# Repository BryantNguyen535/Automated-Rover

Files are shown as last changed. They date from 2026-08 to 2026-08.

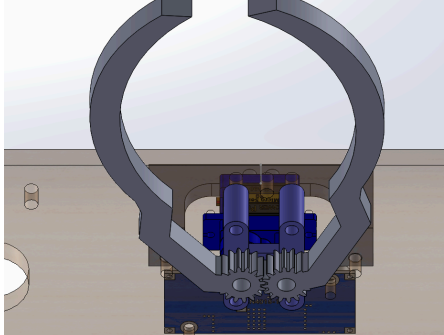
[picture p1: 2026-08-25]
Images/ClawDesign.png

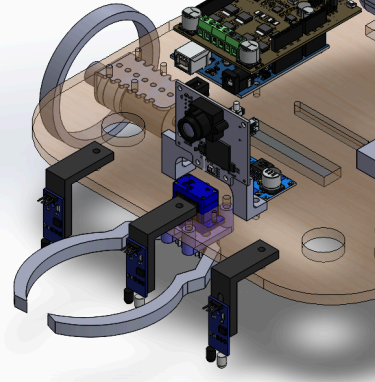
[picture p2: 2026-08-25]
Images/CameraMount.png

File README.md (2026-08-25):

# ZotGPT: Gerbil Portable Transportation

An autonomous line-tracking and object-retrieval rover designed for the ENGR 7B course at the University of California, Irvine (Winter 2023)[cite: 1].

## Team Members
* **Bryant Nguyen** – Team Captain, CAD, Fabrication[cite: 1]
* **Maddox Reyes** – CAD, Electronics[cite: 1]
* **Cole Tateyama** – Electronics, Coding[cite: 1]
* **Rafael Cortes** – Electronics, Coding[cite: 1]
* **Ben Vu** – CAD, Fabrication[cite: 1]

## Overview
ZotGPT is a single-layer, beetle-inspired autonomous rover engineered for speed, stability, and fast line navigation[cite: 1]. The system uses three line-tracking IR sensors to navigate a course and transitions to a Pixy2 camera vision system to center, approach, and retrieve a target colored can using a custom 3D-printed claw[cite: 1].

## Technical Specifications
| Parameter | Value / Specification |
| :--- | :--- |
| **Dimensions** | 15.25 in × 11.27 in[cite: 1] |
| **Chassis Material** | 1/4" Baltic Birch Plywood[cite: 1] |
| **Total Weight** | 1,068.9 g (Stall Limit: 1,650 g)[cite: 1] |
| **Center of Mass** | 5.01 in (width offset), 6.36 in (from back)[cite: 1] |
| **Total Cost** | $263.41 (Budget: <$300)[cite: 1] |
| **Drive Motors** | Dual Pololu 34:1 Gearmotors[cite: 1] |
| **Wheels** | 80mm × 10mm Drive Wheels + 3/4" Caster Wheel[cite: 1] |
| **Microcontroller** | Arduino Uno + Motor Driver Shield[cite: 1] |
| **Sensors & Vision** | Pixy2 Camera, 3× IR Line Sensors[cite: 1] |
| **Actuation** | SG90 Micro Servo (Gear-Driven Claw Mechanism)[cite: 1] |

## Key Features & Design Highlights
* **Optimized Speed & Torque:** Utilizes 34:1 gearmotors paired with 80mm wheels to maximize distance covered per motor rotation while staying below stall weight constraints[cite: 1].
* **Single-Layer Wooden Chassis:** Built with Baltic birch plywood for a lightweight frame and straightforward access to electronics[cite: 1].
* **Adjustable Sensor Placement:** Front-mounted IR sensors positioned close to the ground provide immediate surface readouts, preventing motor signal lag[cite: 1].
* **Elevated Camera Mount:** Custom 3D-printed bracket raises the Pixy2 camera for a high vantage point to detect colored targets reliably[cite: 1].
* **Regulated Power Delivery:** Features an inline buck converter to regulate voltage to the micro servo and eliminate power draw issues[cite: 1].

## System Architecture & Algorithm Design

### State Control Logic
1. **Line Following Mode:**
   * Continuously polls 3 front-mounted IR sensors[cite: 1].
   * If left IR sensor detects line: Steering corrects right[cite: 1].
   * If right IR sensor detects line: Steering corrects left[cite: 1].
   * If middle sensor detects line: Rover drives straight[cite: 1].
   * If all 3 sensors trigger HIGH: Controller switches state to PixyCam tracking[cite: 1].

2. **PixyCam Object Tracking & Grab Mode:**
   * Pixy2 camera processes the pre-programmed color signature of the target[cite: 1].
   * Adjusts left/right motor speeds until target is centered horizontally[cite: 1].
   * Drives forward until object area reaches a predefined threshold distance[cite: 1].
   * Activates SG90 servo to actuate gears and close claw onto the target[cite: 1].

## Bill of Materials (BOM)
| Component | Qty | Extended Price |
| :--- | :---: | :---: |
| Arduino Uno | 1 | $27.60[cite: 1] |
| Motor Driver Shield | 1 | $22.55[cite: 1] |
| Pixy Cam2 | 1 | $69.96[cite: 1] |
| Pololu 34:1 Gearmotors | 1 | $29.95[cite: 1] |
| 80mm x 10mm Wheels | 1 | $9.95[cite: 1] |
| 3D Printing Components | 1 | $32.00[cite: 1] |
| 1/4" Baltic Birch Plywood (16"x10") | 1 | $2.78[cite: 1] |
| Zeee Battery Pack | 1 | $17.50[cite: 1] |
| D-Planet Buck Converter | 1 | $3.75[cite: 1] |
| IR Line Sensors | 3 | $1.65[cite: 1] |
| SG90 Micro Servo | 1 | $1.75[cite: 1] |
| Miscellaneous (Wiring, Switch, Breadboard, Caster) | – | $26.97[cite: 1] |
| **Grand Total (with 7.75% Tax)** | – | **$263.41**[cite: 1] |

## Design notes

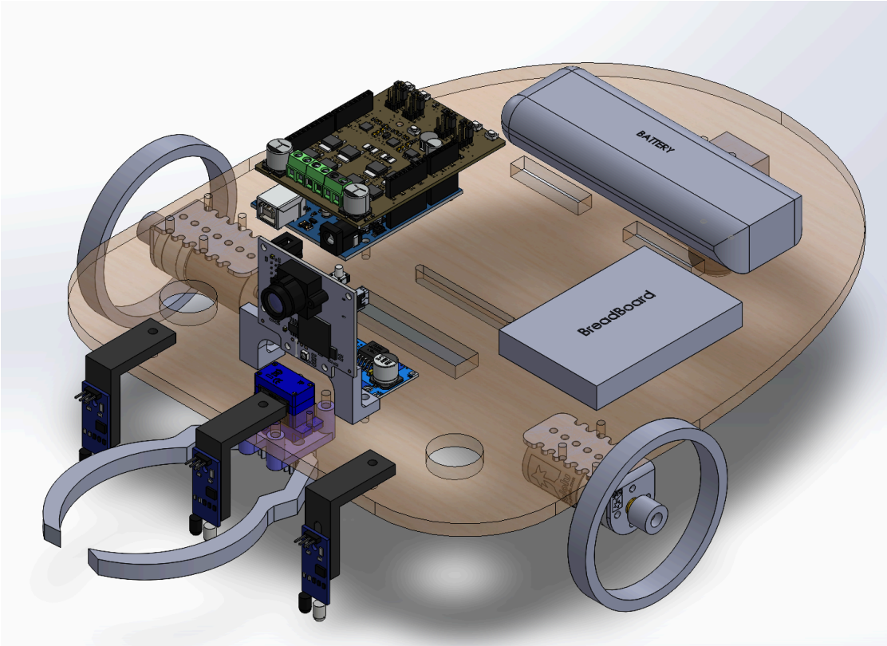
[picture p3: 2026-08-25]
Images/AutomatedRoverFinal.png

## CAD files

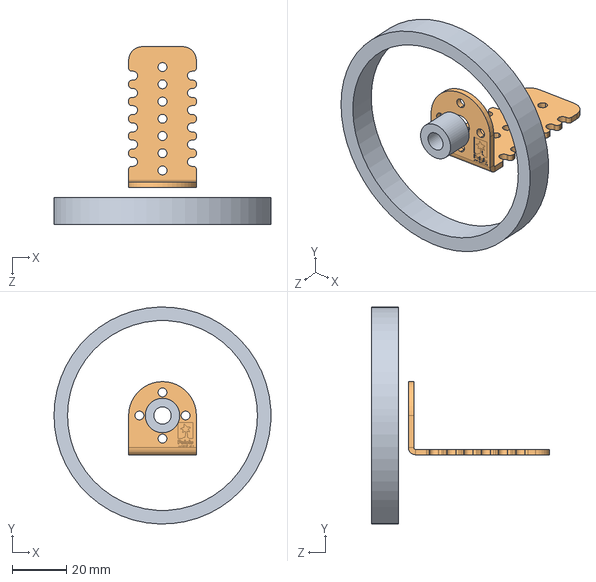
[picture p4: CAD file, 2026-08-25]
CAD files/Gear wheel.SLDASM
80.0 x 80.0 x 65.5 mm
GearmotorBracket
Wheel

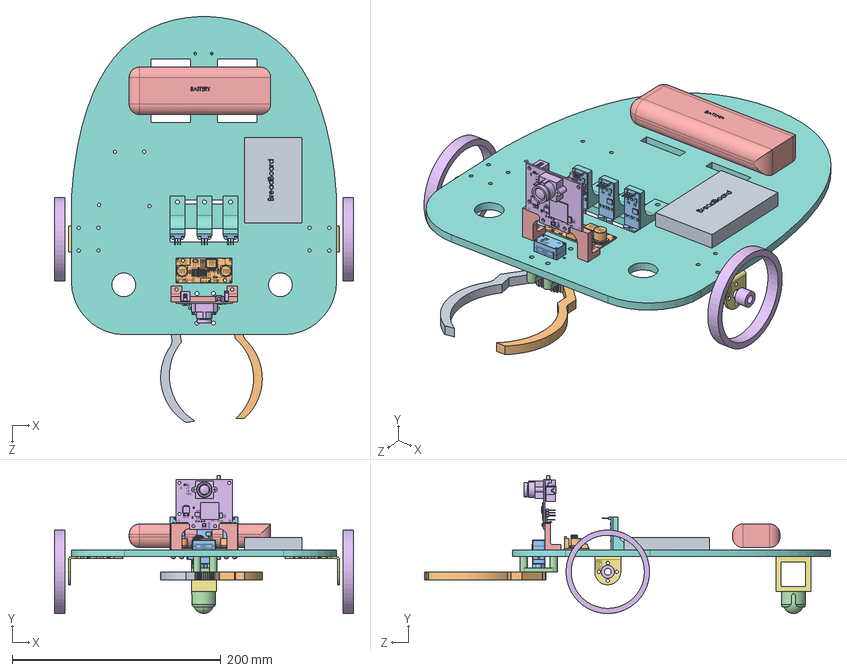
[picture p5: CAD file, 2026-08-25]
CAD files/Automouns rover.SLDASM
286.3 x 132.2 x 389.0 mm
Chassis G
GearmotorBracket x 2
Wheel x 2
part_battery
BallCaster
IRSensor x 3
BuckConverter
BreadBoard
LBracket x 3
Spacer
CMUcam5 Pixy
Double_L_Bracket
Gear_Connector
MicroServo
Gear1
Gear2

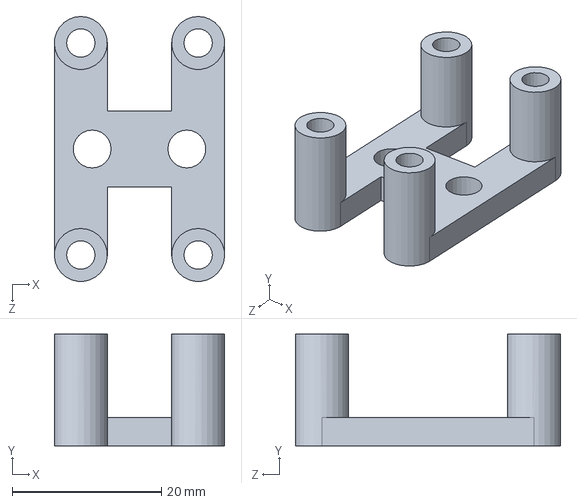
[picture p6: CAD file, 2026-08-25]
CAD files/Gear_Connector.SLDPRT
22.9 x 15.0 x 35.6 mm

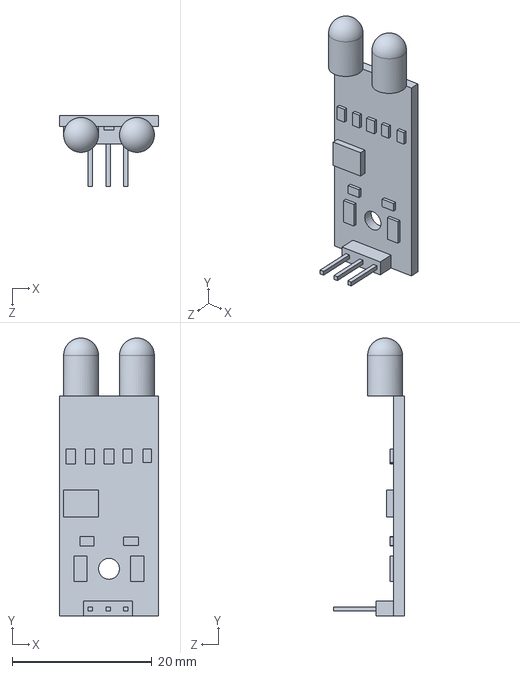
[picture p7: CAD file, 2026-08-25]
CAD files/IRSensor.SLDPRT
14.2 x 39.8 x 10.1 mm

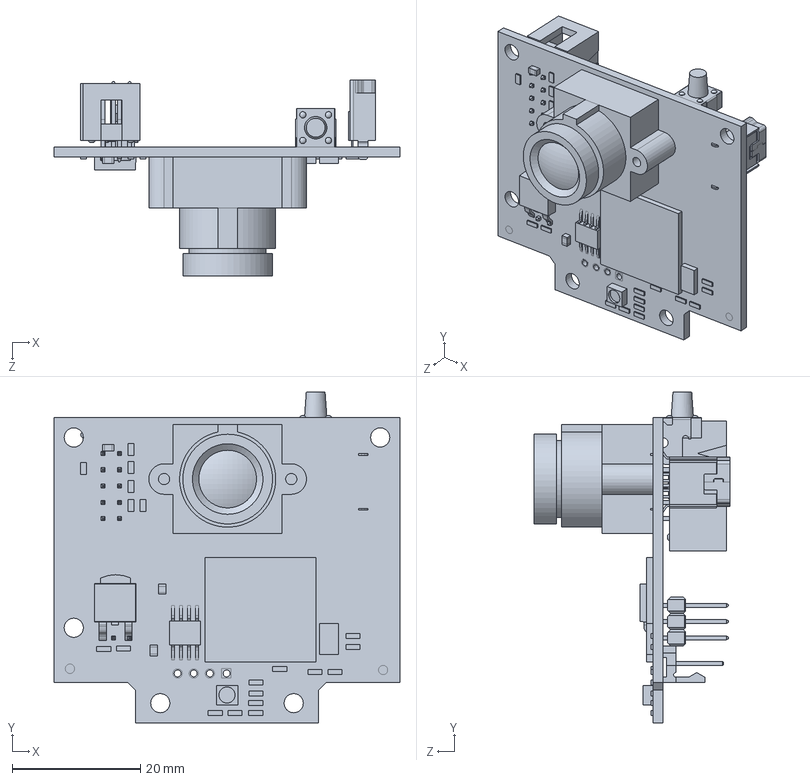
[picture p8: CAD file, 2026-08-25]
CAD files/CMUcam5 Pixy.SLDPRT
54.0 x 51.6 x 30.5 mm

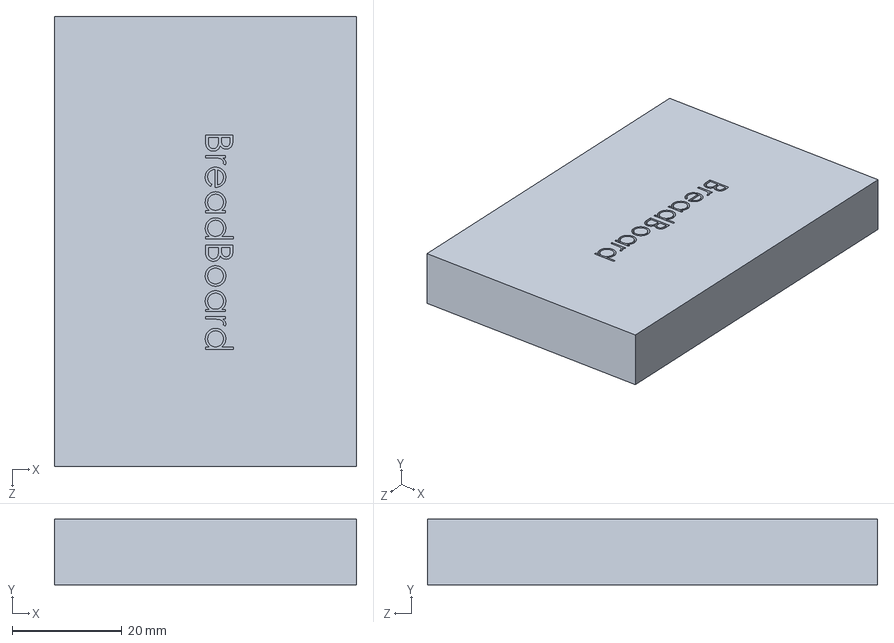
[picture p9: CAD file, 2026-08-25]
CAD files/BreadBoard.SLDPRT
55.0 x 11.9 x 82.0 mm

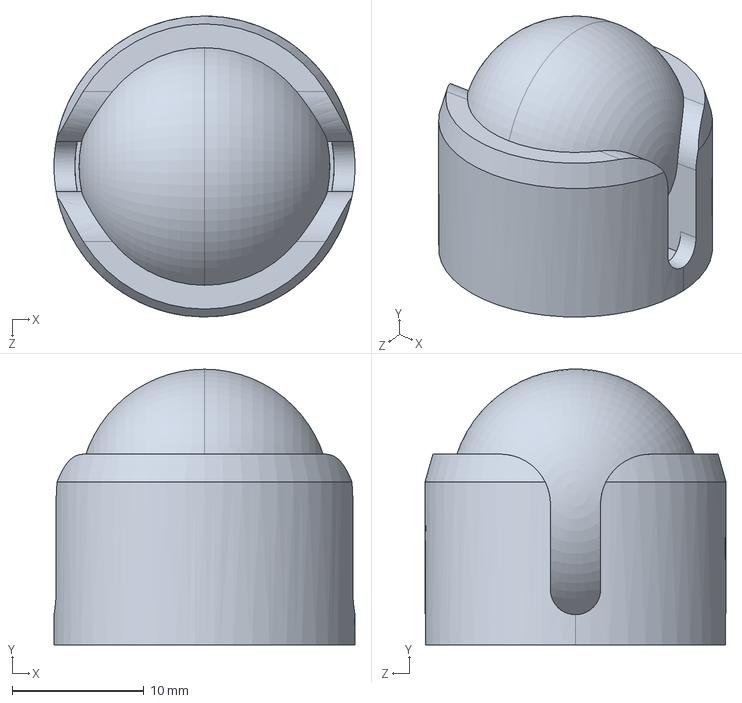
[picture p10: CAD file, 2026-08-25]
CAD files/BallCaster.SLDPRT
22.9 x 20.9 x 22.9 mm

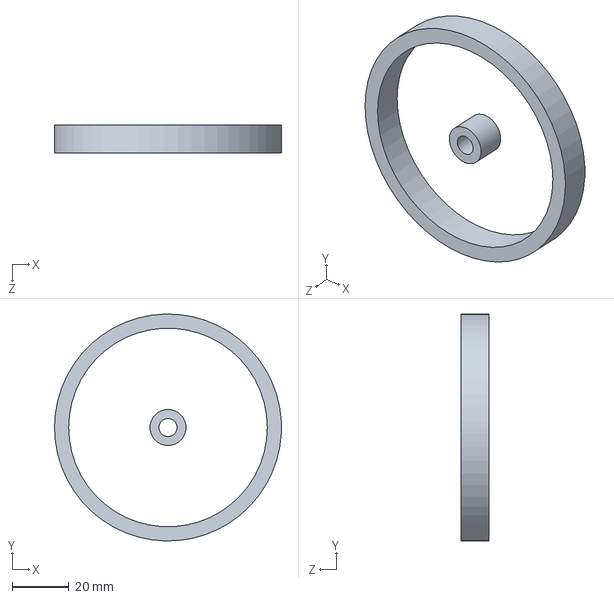
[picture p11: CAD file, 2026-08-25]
CAD files/Wheel.SLDPRT
80.0 x 80.0 x 10.0 mm

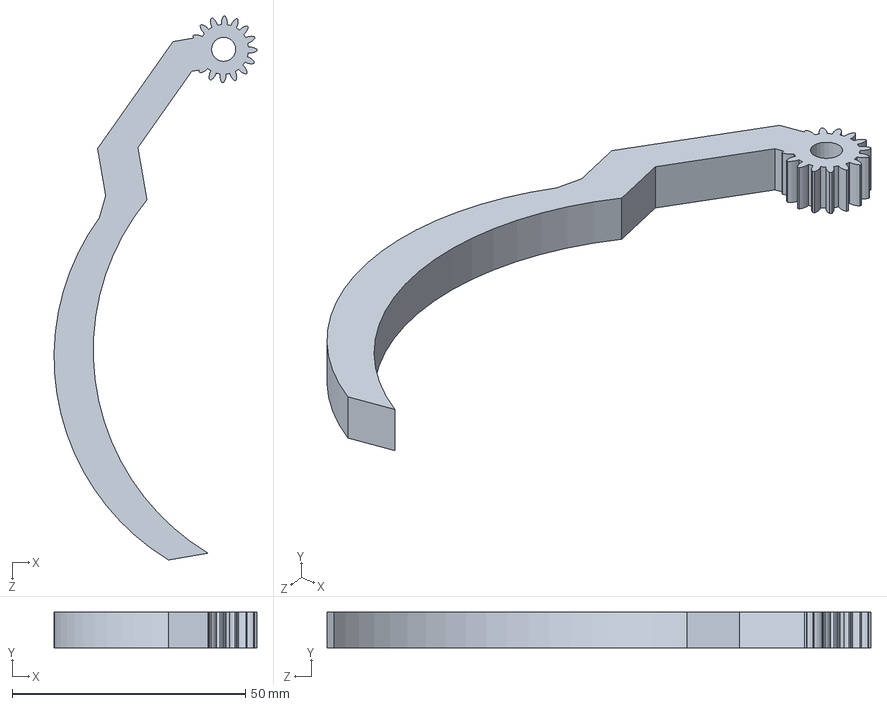
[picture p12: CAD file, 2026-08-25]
CAD files/Gear2.SLDPRT
43.5 x 7.62 x 116.6 mm

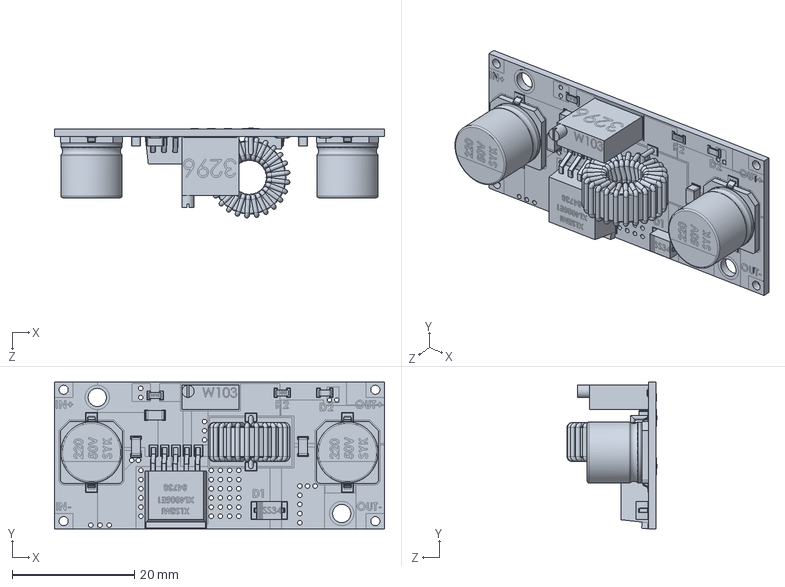
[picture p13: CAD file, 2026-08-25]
CAD files/BuckConverter.SLDPRT
54.0 x 24.0 x 14.8 mm

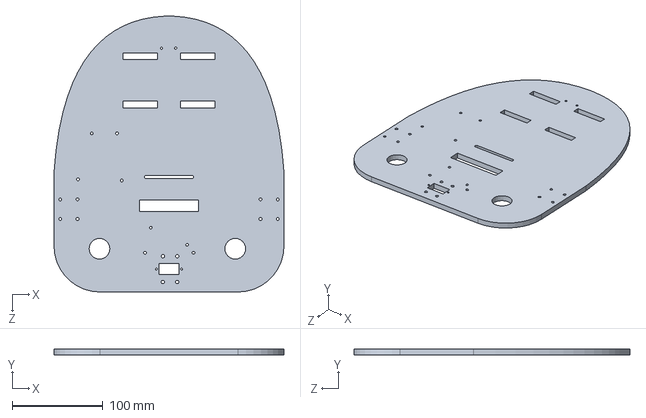
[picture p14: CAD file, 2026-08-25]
CAD files/Chassis G.SLDPRT
254.0 x 6.35 x 304.8 mm

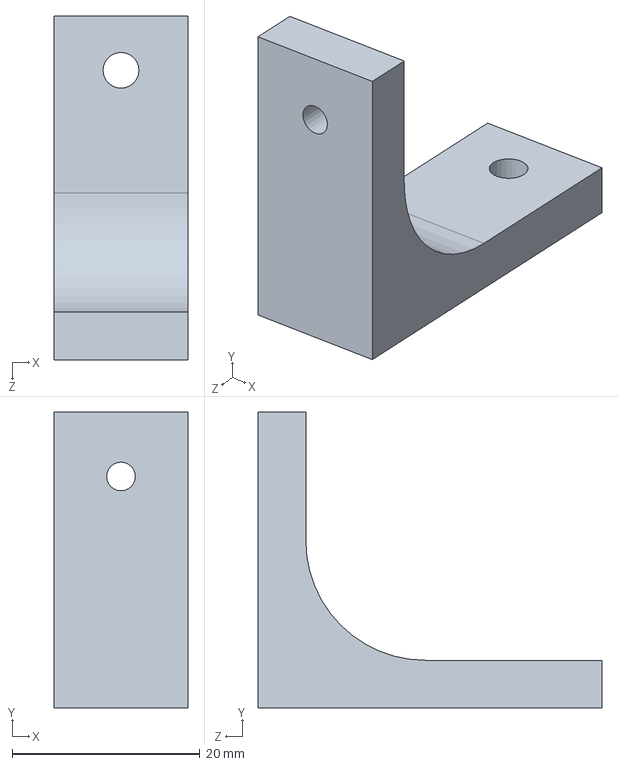
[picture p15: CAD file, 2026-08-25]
CAD files/LBracket.SLDPRT
14.2 x 31.5 x 36.6 mm

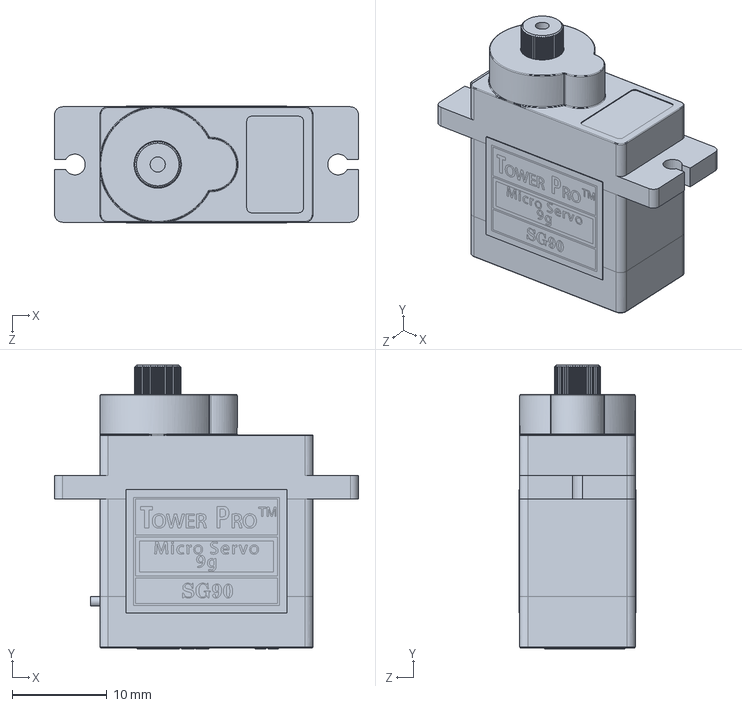
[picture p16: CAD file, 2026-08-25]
CAD files/MicroServo.SLDPRT
32.1 x 30.0 x 12.4 mm

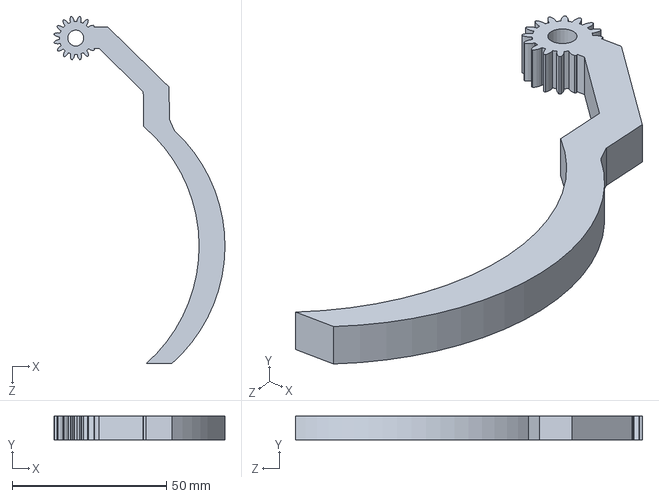
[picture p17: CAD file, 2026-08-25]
CAD files/Gear1.SLDPRT
55.4 x 7.62 x 112.6 mm

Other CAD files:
CAD files/Double_L_Bracket.SLDPRT
CAD files/GearmotorBracket.SLDPRT
CAD files/Spacer.SLDPRT
CAD files/part_battery.SLDPRT

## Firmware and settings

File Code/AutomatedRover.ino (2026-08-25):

/*
Team: ZotGPT
Ben Vu, Bryant Ngo Nguyen, Cole Tateyama, Maddox Anthony Reyes, Rafael Julian Cortes
Last Edit: 2/21/24
This code allows for a rover to follow a line, then switch to a camera to track a object of a specific color and grab it.
*/

#include "CytronMotorDriver.h"
#include <Pixy2.h>
#include <Servo.h>

//Initialize Variables
//General Control
bool Active=true;
//PixyCam Tracking Constants
int trackingRange=10;
int trackingObjSize=150;
int object_x;
int object_width;
//Initialize Sensor Pin #'s
int sensor1=2; //Leftmost Sensor
int sensor2=4;
int sensor3=5; //Rightmost Sensor
int sensor1OUT;
int sensor2OUT;
int sensor3OUT;
//Initialize Servo Pin #'s
int S1=9;
//Motor Setup
CytronMD motor1(PWM_DIR, 3, 8); //LEFT MOTOR
CytronMD motor2(PWM_DIR, 6, 7); //RIGHT MOTOR
//Servo Setup
Servo servo;
//PIXYCAM Setup
Pixy2 pixy;

void setup()
{
Serial.begin(19200);
pinMode(sensor1, INPUT);
pinMode(sensor2, INPUT);
pinMode(sensor3, INPUT);
servo.attach(9);
pixy.init();
pixy.changeProg("color_connected_components");
servo.write(0);
}

void loop() //Read, Calc, Move
{
  while(Active==true) //code loops the linetrack code until it reaches the end of the track, then switches to the PixyCam code
  {
    lineTrack();
  } 
  PixyCamTrack(); 
}

void lineTrack() //Line tracking code for rover to follow line
{
  sensor1OUT=digitalRead(sensor1);
  sensor2OUT=digitalRead(sensor2);
  sensor3OUT=digitalRead(sensor3);
  //Sensor Read: *HIGH=Detects line  Negative = Left  Positive = Right
  if(sensor1OUT==LOW &&  sensor3OUT==LOW) //Detects no line on left/right sensors
  {
    motor1.setSpeed(120);
    motor2.setSpeed(120);
  }

  if(sensor1OUT==LOW &&  sensor3OUT==HIGH) //Detects when veering right
  {
    motor1.setSpeed(-200); //turn left
    motor2.setSpeed(150);
  }

  if(sensor1OUT==HIGH &&  sensor3OUT==LOW) //Detects when veering left
  {
    motor1.setSpeed(150); //turn right
    motor2.setSpeed(-200);
  }

  if(sensor1OUT==HIGH && sensor2OUT==HIGH && sensor3OUT==HIGH) //Detects line at end of track
  {
    motor1.setSpeed(0);
    motor2.setSpeed(0);
    Active=false; //disable line tracking code
  }
}

void PixyCamTrack() //Handles PixyCam code to track object + move toward it
{
  pixy.ccc.getBlocks(); //All blocks within frame

  object_x=pixy.ccc.blocks[0].m_x; //Track x value of largest block
  object_width=pixy.ccc.blocks[0].m_width; //Track width of largest block

  if(object_x<(157-trackingRange)) //If object is left of midline + theshold value
  {
    motor1.setSpeed(75); //turn Right
    motor2.setSpeed(-75); 
    servo.write(0);
  }
  else if(object_x>(157+trackingRange)) //If object is right of midline + threshold value
  {
    motor1.setSpeed(-75); //turn Left
    motor2.setSpeed(75); 
    servo.write(0);
  }
  else if(object_width<trackingObjSize) //If object is smaller than threshold size
  {
    motor1.setSpeed(100); //Straight
    motor2.setSpeed(100);
    servo.write(0);
  }
  if(object_width>trackingObjSize) //If object is greater than threshold size
  {
    motor1.setSpeed(0); //Stop
    motor2.setSpeed(0);
    servo.write(180); //Servo Motor close
    delay(500);
  }
}
